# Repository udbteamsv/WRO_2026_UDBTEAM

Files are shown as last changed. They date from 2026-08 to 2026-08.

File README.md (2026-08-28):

# WRO_2026_UDBTEAM
Proyecto del vehículo autónomo para WRO 2026 - Futuros Ingenieros
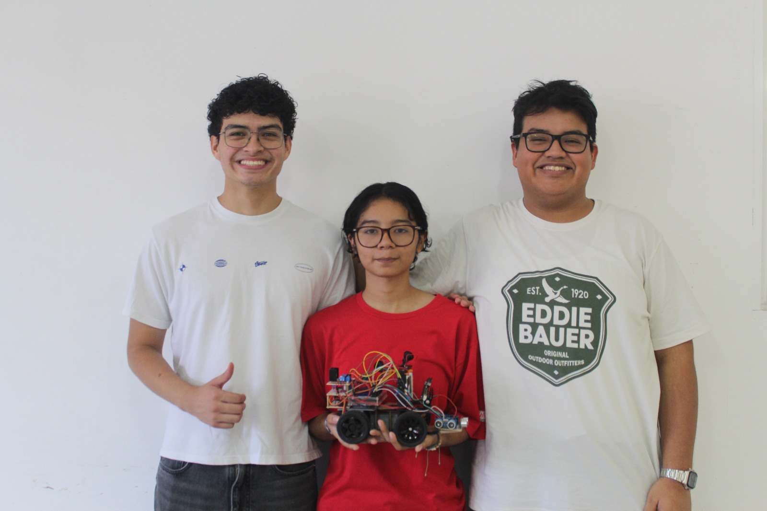
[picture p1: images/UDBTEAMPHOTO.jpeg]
UDB TEAM


# Self-Driving Car Challenge Documentation

## Introduction
This repository is the documentation for the self-driving car challenge designed by the Universidad Don Bosco students to participate in the 2026 World Robot Olympiad Future Engineers. This is a competition where a self-driving car should complete 2 challenges, the first is being able to take 3 laps around a square course and stop and the second is taking the same course but with red obstacles that the car should pass on the right and green obstacles on the left. The car steering direction is controlled by servo motor MG90S, the traction is controlled by an electric motor connected to by gears that duplicate torque and the detection of obstacles is done trough a Huskylens camara, ultrasonic sensors and a color sensor. The embedded system is controlled by an Arduino Mega and is powered by 2 18650 li-ion batteries regulated to 6V to supply the servo motor  and 4 19640 li-ion batteries to supply the electric motor.

---

## Traction
Traction is controlled by a motor driver L298N connected to an electric motor with a pair of gears that duplicate torque. These parts where designed by the team and the stl file are available in this repository. We chose L298 because it can be powered with up to 35V and 2A and we are powering it with a 16V regulated to 12V to ensure a constant voltage to electric motor [1].

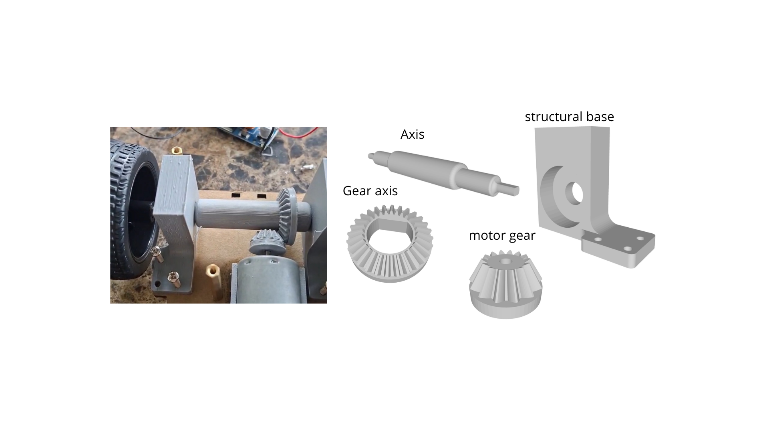
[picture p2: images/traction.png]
Traction System


---

## Steering
The steering is controlled by a MG90S servo motor using some parts of the LK KOKOINO Rear-Wheel drive robot car kit [2].
the MG90S has the same dimensions as the sg90 servo and works the same,  but has metal gears that improve durability and torque.
---

## Decision Making

### Open Challenge
The ultrasonic sensors on the left and right side of the car are used to measure how close to the center of the track the car is and change the steering angle to maintain the car in the center. When the sum of the distances is larger than 130 cm the car is likely near the corner, so it steers to the direction with the largest distance. While the car is turning the readings are ignored for a fixed amount of time and then the loop continues.

here is the youtube link of the first time the car did the open challenge: https://www.youtube.com/watch?v=LxlPVEr9SCA

### Obstacle Challenge
The color sensor  checks every iteration of the loop for the orange and blue lines to know if it must turn if not it checks for the nearest obstacle detected  by the camera, stores the color cube in a variable and calculates how far is the nearest obstacle from the center in the horizontal axis this distance is used to keep the nearest cube in front of the car, then the car approaches the  obstacle using the front ultrasonic sensor to avoid getting to close to it and then it turns right or left depending on the last color stored in memory then the code repeats.

---

### references 

[1] L298N Module datasheet: https://de.scribd.com/document/482249360/Arduino-L298N-DATASHEET
[2]  LK KOKOINO Rear-Wheel drive robot car kit: https://www.amazon.com/dp/B0FC2X2LVZ?lv=shuf&channelId=500&plpRedirect=mhFallback

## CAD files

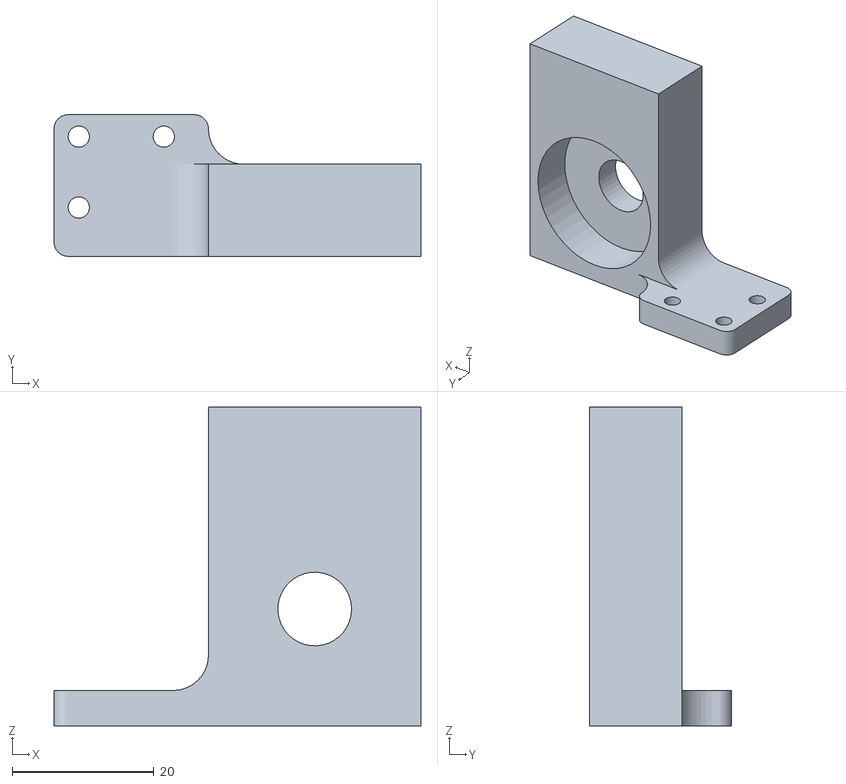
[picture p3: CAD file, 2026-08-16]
models/BaseRodamientoIzqNew.STL
51.8 x 20.0 x 45.0

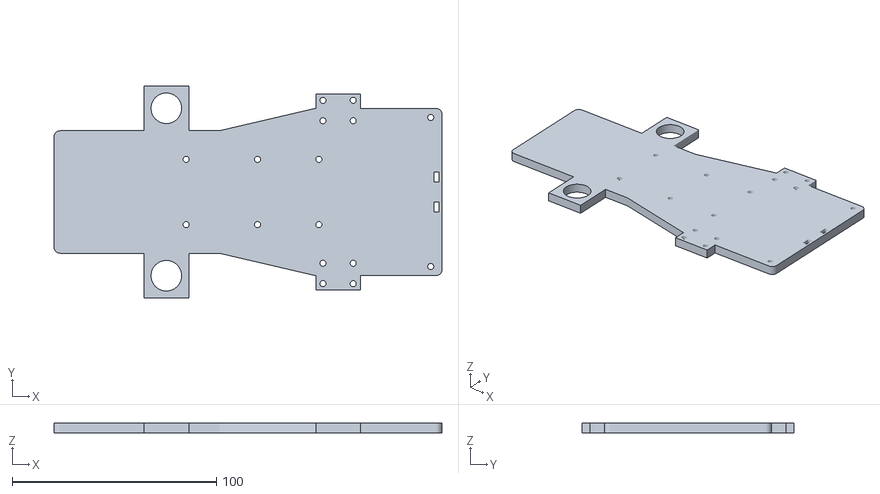
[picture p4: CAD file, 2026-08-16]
models/ChasisBase.STL
190.0 x 104.0 x 5.00

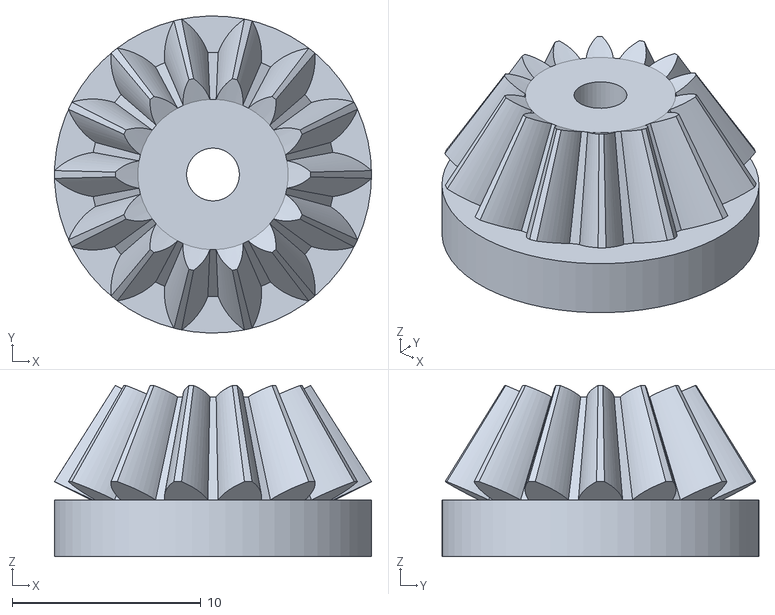
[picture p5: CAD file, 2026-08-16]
models/EngranajeMotorNew.STL
16.8 x 16.8 x 9.07

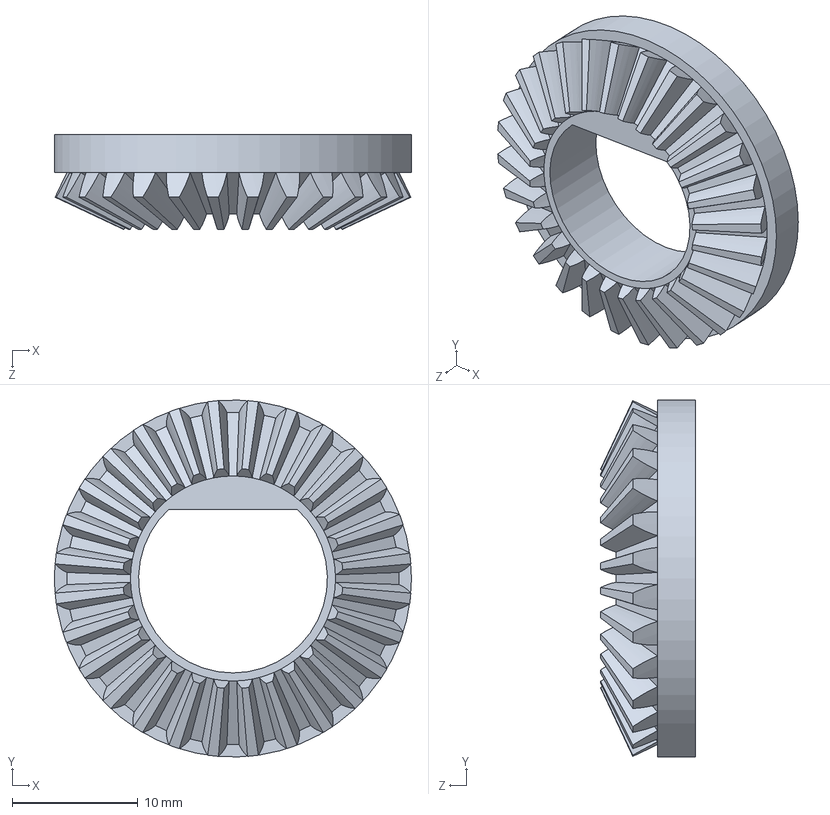
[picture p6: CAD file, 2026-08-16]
models/EngranajeEjeNew.SLDPRT
28.4 x 28.3 x 7.51 mm

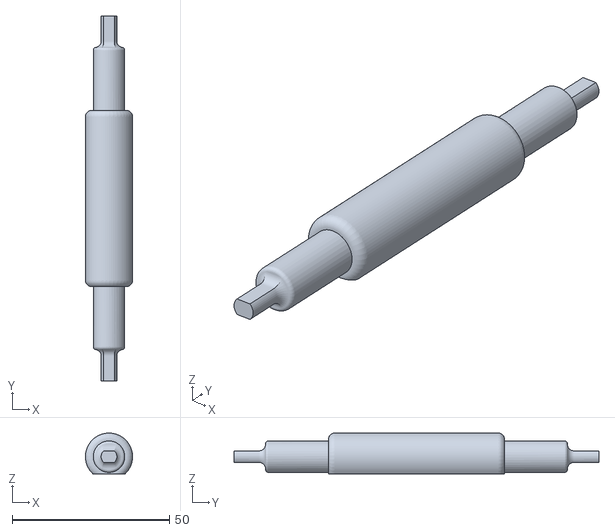
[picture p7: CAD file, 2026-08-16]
models/EjeNew.STL
15.0 x 116.0 x 13.0

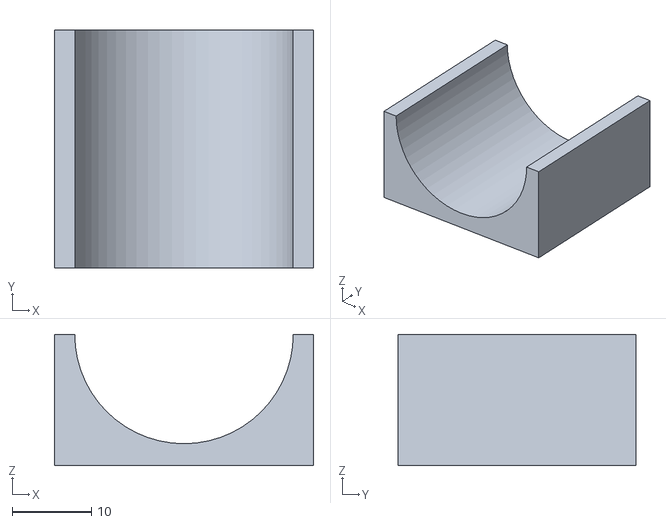
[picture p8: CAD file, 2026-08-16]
models/Soporte_Motor.STL
32.6 x 30.0 x 16.5

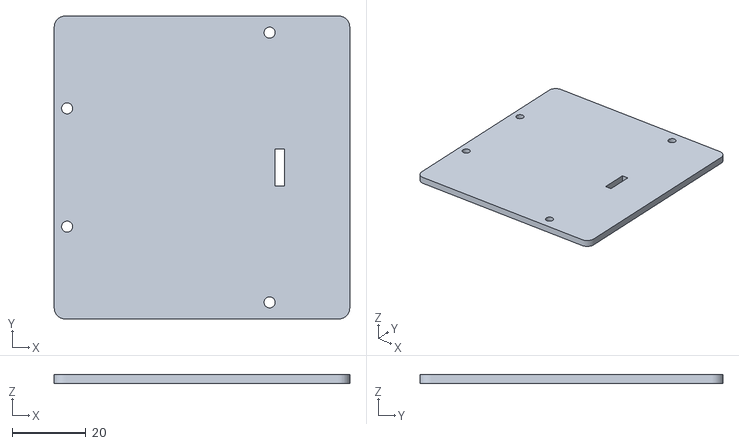
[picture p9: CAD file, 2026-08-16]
models/NuevaTapa.STL
80.0 x 82.0 x 2.50

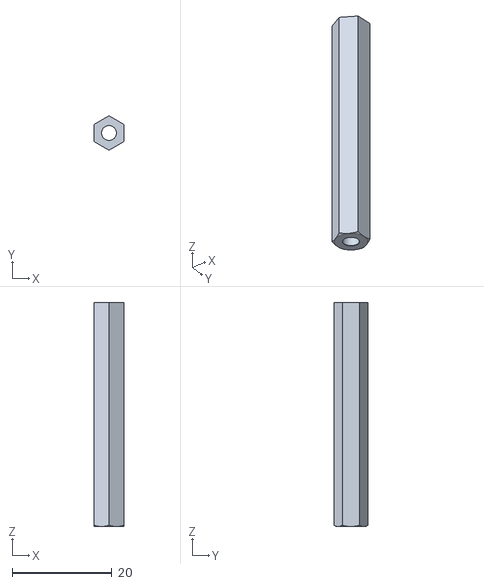
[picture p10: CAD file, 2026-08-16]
models/92080A030_Zinc-Plated Brass Female Threaded Hex Standoff.STL
6.00 x 6.93 x 45.0

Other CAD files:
models/BaseRodamientoDerNew.STL
models/EngranajeEjeNew.STL

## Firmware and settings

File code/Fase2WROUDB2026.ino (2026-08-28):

#include <Servo.h>
#include <SPI.h>
#include <Wire.h>
#include <Adafruit_GFX.h>
#include <Adafruit_SSD1306.h>
#include "HUSKYLENS.h"

//PANTALLA OLED
Adafruit_SSD1306 display = Adafruit_SSD1306(128, 32, &Wire);

byte a = 0;
byte a_anterior = 255;

//CÁMARA HUSKYLENS
HUSKYLENS huskyLens;
const int ID_VERDE = 2; 
const int ID_ROJO  = 1; 

const int CENTROX = 160; 
const int AREAMIN = 600;  // Área mínima para considerar un cubo válido
float Kp_Camara = 1;   // Constante proporcional para centrar el cubo suavemente
bool e=true;
//FILTRO DE ULTRASÓNICOS 
const bool FiltroUS = 1;
const int buffersize = 7;
int puntero = 0;

// Variables sensores ultrasónicos 
const int echoI = 22; const int trigI = 23;
const int echoD = 24; const int trigD = 25;
const int echoF = 26; const int trigF = 27;

double duracionR, distanciaR;
double duracionL, distanciaL;
double duracionF, distanciaF;

// Buffers 
double dRbuffer[buffersize]={};
double dLbuffer[buffersize]={};
double dFbuffer[buffersize]={};
double sumdR;
double sumdL;
double sumdF;

const unsigned long TIMEOUT_US = 30000; 

// Variables L298N 
const int ENA = 2; 
const int IN1 = 4; 
const int IN2 = 3; 

// Variables servo y control PD 
Servo direccionServo;
const int pinServo = 9;
int centroServo = 95; 

// Constantes PID de Muros
double Kp = 3;   // funciona: 2.5
double Kd = 1.5; // funciona: 1.5 
int errorAnterior = 0;

// variables de estado 
// 0=PD Muros, 1=Girando Esquina, 2=Enfriamiento Esquina, 3=Acercando a Cubo, 4=Esquivando
int estadoRobot = 0; 
unsigned long tiempoInicioGiro = 0;
bool arranque = false;
unsigned long tiempoUltimoGiro = 0;

const unsigned long TIEMPO_BLOQUEO_GIRO = 750; 
const unsigned long TIEMPO_DURACION_GIRO = 2500; 

// variables 
const double distanciaEsquive = 15.0; // Distancia para iniciar maniobras
int idCuboObjetivo = 0;
unsigned long tiempoInicioEsquive = 0;

int contador = 0;
int giro = 0;
bool contactivado = 1;
unsigned long tiempocontador;

// Variables finales
unsigned long tiempoFinVuelta = 0;
bool terminandoVuelta = false;

void setup() {
  Serial.begin(115200);
  Wire.begin();

  Serial.println("OLED intialized");
  display.begin(SSD1306_SWITCHCAPVCC, 0x3C); 

  display.display();
  display.clearDisplay();
  display.display();
  display.setTextSize(3);
  display.setTextColor(WHITE);
  
  direccionServo.attach(pinServo);
  direccionServo.write(centroServo);

  pinMode(trigI, OUTPUT); pinMode(echoI, INPUT);
  pinMode(trigD, OUTPUT); pinMode(echoD, INPUT);
  pinMode(trigF, OUTPUT); pinMode(echoF, INPUT);

  pinMode(ENA, OUTPUT);
  pinMode(IN1, OUTPUT);
  pinMode(IN2, OUTPUT);

  // Inicialización de la HuskyLens
  while (!huskyLens.begin(Wire)) {
    Serial.println(F("Falla al conectar HuskyLens... Reintentando"));
    delay(500);
  }
  huskyLens.writeAlgorithm(ALGORITHM_COLOR_RECOGNITION);

  for(int h = 0; h <= buffersize*2; h++){
    Ultrasonico();
  }
  Serial.println("Iniciando WRO 2026 - Fase Integrada...");
  delay(2000);
}

void loop() {
  
  // 1. Actualización de pantalla
  if (a != a_anterior) {
    display.clearDisplay();
    display.setCursor(0, 0);
    display.print("v: ");
    display.println(a);
    display.display();
    a_anterior = a;
  }
   
  // 2. Lógica de parada final
  if (contador >= 12 && !terminandoVuelta) {
    terminandoVuelta = true;
    tiempoFinVuelta = millis(); 
    Serial.println("Vuelta completada + 6 seg");
  }

  if (terminandoVuelta && (millis() - tiempoFinVuelta >= 6000)) { 
    parar();
    Serial.println("Tiempo final agotado. Carro detenido permanentemente.");
    while(1); 
  }
  
  if(contactivado == 0 && (millis()-tiempocontador) >= 8000){
   contactivado = 1; 
  }
  
  // 3. Lectura de sensores constante
  Ultrasonico();


  // Lectura de la camara Huskylens
 
  int idCuboDetectado = 0;
  int xCuboDetectado  = 0;
  
  if (huskyLens.request()) {
    int maxArea = 0;
    while (huskyLens.available()) {
      HUSKYLENSResult result = huskyLens.read();
      if (result.command == COMMAND_RETURN_BLOCK) {
        int areaActual = result.width * result.height;
        if (areaActual > maxArea && areaActual > AREAMIN) {
          maxArea = areaActual;
          idCuboDetectado = result.ID;
          xCuboDetectado  = result.xCenter;
         // Serial.println(areaActual);
        }
      }
    }
  }

  // --- 4. estados 
  switch (estadoRobot) {
        // estado 0: Avance y PD
=
    case 0: 
      // 1ro. Prioridad esquinas
      if (((distanciaR + distanciaL) > 95 && ((distanciaF > 50 && distanciaF < 60) || (distanciaF > 30 && distanciaF < 40))) && contactivado == 1) {
        arranque = false;
        if ((distanciaR > distanciaL && giro == 0) || giro == 1) {
          giro = 1;
          direccionServo.write(65); // Derecha
          Serial.println("INICIANDO GIRO DERECHA");
        } 
        else if ((distanciaL > distanciaR && giro == 0) || giro == 2) {
          giro = 2;
          direccionServo.write(125); // Izquierda
          Serial.println("INICIANDO GIRO IZQUIERDA");
        }
        
        estadoRobot = 1; 
        tiempoInicioGiro = millis();
        contador++;
        a++;
        contactivado = 0;
        tiempocontador = millis();
        e=false;

      } 
      // 2do. Prioridad cámara: si se detecta un cubo cambia el estado
      else if (idCuboDetectado != 0 && e == true) {
        idCuboObjetivo = idCuboDetectado;
        estadoRobot = 3; // Pasamos al estado de Acercamiento
        Serial.println("Cubo Detectado -> Cambiando a Estado 3 (Acercamiento)");
      }
      // 3ro. Si no hay nada, hacemos control PD normal
      else {
        if (arranque == true) {
          Avan(110); 
          direccionServo.write(centroServo);
        } else {
          if (distanciaF >= 60 && distanciaF < 90) {
            Avan(110); 
            direccionServo.write(centroServo);
          } else {
            Avan(110); 
            int error = distanciaL - distanciaR;
            float P = error;
            float D = error - errorAnterior;
            
            int ajuste = (Kp * P) + (Kd * D);
            int nuevoAngulo = centroServo + ajuste; 
            
            if (nuevoAngulo > 115) nuevoAngulo = 115;
            if (nuevoAngulo < 75) nuevoAngulo = 75;
            
            direccionServo.write(nuevoAngulo);
            errorAnterior = error;
          }
        }
      }
      break;


    // Estado 1: Giro en esquina

    case 1:
      Avan(110);
      if ((millis() - tiempoInicioGiro >= TIEMPO_DURACION_GIRO) || distanciaF > 170) {
        Serial.println("FIN DEL GIRO. Entrando a enfriamiento.");
      
        delay(500); 
        if(distanciaF > 30 && distanciaF < 40){ delay(250); }
        Ultrasonico();
        estadoRobot = 2; 
        tiempoUltimoGiro = millis();
      }
      break;

    
    // Estado 2: avanzar al frente 
   
    case 2:
      direccionServo.write(centroServo); 
      Avan(110);
      if (millis() - tiempoUltimoGiro >= TIEMPO_BLOQUEO_GIRO) {
        Serial.println("avanzar y regresar al PD");
        estadoRobot = 0; 
        errorAnterior = 0; 
        e=true;
      }
      break;

 
    // Estado 3: acercarse al cubo.

    case 3:
      Avan(110);
      
      //iniciamos el esquive 
      if (distanciaF <= distanciaEsquive) {
        Serial.println("Distancia alcanzada. Iniciando ESQUIVE (Estado 4)");
        estadoRobot = 4;
        tiempoInicioEsquive = millis();
      } 
      // pd para central el cubo utilizando la cámara
      else if (idCuboDetectado != 0) {
        // Cálculo del error: CENTRO (160) - Posición del Cubo
        // Si el cubo está en 100 (Izquierda), el error es +60.
        int errorCamara = CENTROX - xCuboDetectado; 
        
        int ajusteCamara = errorCamara * Kp_Camara;
        int nuevoAngulo = centroServo + ajusteCamara;
        
        // limitar giros bruscos
        if (nuevoAngulo > 115) nuevoAngulo = 115;
        if (nuevoAngulo < 75) nuevoAngulo = 75;
        
        direccionServo.write(nuevoAngulo);
      } 
      // al perder el cubo volver a PD
      else {
        Serial.println("Cubo perdido. Volviendo a Estado 0");
        estadoRobot = 0;
        errorAnterior = 0;
      }
      break;


    // Estado 4: Maniobra de esquive de cubos

    case 4:
      Avan(110);
      unsigned long tiempoEsquivando = millis() - tiempoInicioEsquive;
      
      if (idCuboObjetivo == ID_VERDE) {
        // Rojo -> Pasar por la Izquierda (Giro agresivo Izquierda, luego Derecha)
        if (tiempoEsquivando < 1300) {
          direccionServo.write(125); // Giro Fuerte Izquierda
        } 
        else if (tiempoEsquivando < 2300) {
          direccionServo.write(70);
          delay(200);
          direccionServo.write(centroServo);  // recto
        } 
        else if (tiempoEsquivando < 3300) {
          direccionServo.write(70);  // Contravolante para enderezar
        }
        else {
          estadoRobot = 0;
          errorAnterior = 0; // Para que el PD de muros inicie
          Serial.println("Fin de Esquive VERDE. Volviendo al PD.");
        }
      } 
      else if (idCuboObjetivo == ID_ROJO) {
        // Verde -> Pasar por la Derecha (Giro agresivo Derecha, luego Izquierda)
        if (tiempoEsquivando < 1300) {
          direccionServo.write(65);  // Giro fuerte a la derecha
        } 
        else if (tiempoEsquivando < 2300) {
          direccionServo.write(120);
          delay(200);
          direccionServo.write(centroServo);  // recto
        }
        else if (tiempoEsquivando < 3300) {
          direccionServo.write(120); // enderezar
        } 
        else {
          estadoRobot = 0;
          errorAnterior = 0; // Ayuda al PD de muros iniciar 
          Serial.println("Fin de Esquive ROJO. Volviendo al PD.");
        }
      }
      break;
  }
}

// Funciones de movimiento
void Avan(int velocidad) {
  analogWrite(ENA, velocidad);
  digitalWrite(IN1, HIGH);
  digitalWrite(IN2, LOW);
}

void retro(int velocidad) {
  analogWrite(ENA, velocidad);
  digitalWrite(IN1, LOW);
  digitalWrite(IN2, HIGH);
}

void parar() {
  analogWrite(ENA, 0);
  digitalWrite(IN1, LOW);
  digitalWrite(IN2, LOW);
}

// Función de sensores ultrasónicos 
void Ultrasonico() {
  // Lado Derecho
  digitalWrite(trigD, LOW); delayMicroseconds(2);
  digitalWrite(trigD, HIGH); delayMicroseconds(10);
  digitalWrite(trigD, LOW);
  duracionR = pulseIn(echoD, HIGH, TIMEOUT_US);
  distanciaR = (duracionR == 0) ? 155 : duracionR * 0.034 / 2; 
  
  if(FiltroUS == 1){
    sumdR -= dRbuffer[puntero];
    sumdR += distanciaR;
    dRbuffer[puntero] = distanciaR;
    distanciaR = sumdR/buffersize;
  }
  if(distanciaR >= 150) distanciaR = 150; 

  // Lado Izquierdo
  digitalWrite(trigI, LOW); delayMicroseconds(2);
  digitalWrite(trigI, HIGH); delayMicroseconds(10);
  digitalWrite(trigI, LOW);
  duracionL = pulseIn(echoI, HIGH, TIMEOUT_US);
  distanciaL = (duracionL == 0) ? 155 : duracionL * 0.034 / 2;

  if(FiltroUS == 1){
    sumdL -= dLbuffer[puntero];
    sumdL += distanciaL;
    dLbuffer[puntero] = distanciaL;
    distanciaL = sumdL/buffersize;
  }
  if(distanciaL >= 150) distanciaL = 150; 

  // Frente
  digitalWrite(trigF, LOW); delayMicroseconds(2);
  digitalWrite(trigF, HIGH); delayMicroseconds(10);
  digitalWrite(trigF, LOW);
  duracionF = pulseIn(echoF, HIGH, TIMEOUT_US);
  distanciaF = (duracionF == 0) ? 90 : duracionF * 0.034 / 2;

  // Comentado para no saturar 
  // Serial.print("Izquierda: "); Serial.print(distanciaL);
  // Serial.print(" cm  |  Frente: "); Serial.print(distanciaF);
  // Serial.print(" cm  |  Derecha: "); Serial.print(distanciaR);
  // Serial.println(" cm");

  if(FiltroUS == 1){
    puntero ++;
    puntero %= buffersize;
  }
}

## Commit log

2026-08-14 opentrack_v1 and files location fixes
    [Fase1WROUDB2026.ino, Fase2WROUDB2026.ino]
2026-08-15 added stl files and file location changes
2026-08-16 real stl updload
    [92080A030_Zinc-Plated Brass Female Threaded Hex Standoff.STL, BaseRodamientoDerNew.STL, BaseRodamientoIzqNew.STL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]
